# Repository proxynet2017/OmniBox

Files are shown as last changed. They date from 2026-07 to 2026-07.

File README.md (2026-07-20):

<div align="center">

# OmniBox

**A public non-commercial ECU diagnostics and reprogramming interface platform**

OmniBox V1 is a KiCad-based USB-to-OBD and bench ECU interface designed for
serious diagnostic, protocol research and ECU reprogramming workflows.

OmniBox V1 board render






</div>

## What It Is

OmniBox is a public hardware and firmware project for building a capable vehicle
interface around documented, inspectable design files. The V1 board is intended
to be more than a simple USB-to-CAN adapter: it combines isolated USB, protected
vehicle power, multi-channel CAN/CAN-FD, K-line, J1850/SWCAN hardware stages,
programmable FEPS generation, measurement feedback and an OBD routing matrix.

The hardware is designed to support ECU communication and reprogramming
workflows both through OBD and on the bench. That includes the physical-layer
building blocks normally needed for flashing-oriented work: controlled vehicle
side power, routable diagnostic lines, FEPS generation, CAN/CAN-FD, K-line and
feedback measurements. Firmware support is still in early development, so this
should be read as a hardware capability and project direction, not a claim that
all reprogramming workflows are already validated.

## Why It Exists

Most low-cost diagnostic interfaces are closed, narrow or difficult to inspect.
OmniBox takes the opposite approach:

| Goal | What V1 Provides |
|---|---|
| Inspectable hardware | KiCad schematic, PCB, footprints, BOM and production files |
| Real ECU work | OBD and bench-oriented routing, FEPS and multiple bus interfaces |
| Electrical resilience | Isolation, TVS protection, protected power input and automotive parts |
| Firmware headroom | STM32H723 Cortex-M7 with native FDCAN and enough RAM for queues/traces |
| Community development | Public J2534/ELM327 firmware base and host-side test tools |
| Reproducibility | Gerbers, drill files, enclosure files and release assets |

## Current Releases

| Package | Version | Link |
|---|---:|---|
| Hardware manufacturing package | 1.0 beta | [hardware-v1.0-beta](https://github.com/proxynet2017/OmniBox/releases/tag/hardware-v1.0-beta) |
| Firmware source and binaries | 0.1 dev | [firmware-v0.1-dev](https://github.com/proxynet2017/OmniBox/releases/tag/firmware-v0.1-dev) |

Firmware release assets include `.elf`, `.bin`, `.hex`, `.map` and source
archive files.

## 3D Preview

The board can be inspected as a rendered image or as a STEP model:

- [board render PNG](docs/images/omnibox-v1-board-iso-complete.png)
- [board STEP model](docs/3d/omnibox-v1-board-complete.step)

## Hardware Highlights

| Area | OmniBox V1 |
|---|---|
| Host connection | Isolated USB Full-Speed with WinUSB and CDC interfaces |
| MCU | STM32H723ZGTx Cortex-M7 |
| CAN / CAN-FD | Five routable CAN-capable channels |
| CAN physical layer | NXP TJA1463 automotive CAN SIC transceivers |
| External CAN-FD | Microchip MCP2518FD controllers over SPI |
| K-line | Three ST L9637D ISO 9141-2 / ISO 14230 channels |
| SWCAN / J1850 | Dedicated Single-Wire CAN, VPW and PWM hardware stages |
| FEPS | Programmable boost stage with DAC control and ADC/current feedback |
| Routing | Relay and protected analog-switch matrix for OBD/J1962 pins |
| Protection | SM8S24A TVS, ESD/TVS protection, filtering and protected power input |
| Isolation | Isolated power, isolated I2C and digital isolators |
| Mechanical | Sheet-metal enclosure plus STEP/STL printable/mechanical files |

## Reprogramming-Oriented Design

OmniBox V1 was designed with ECU flashing and calibration workflows in mind,
including both in-vehicle OBD work and bench harness work.

Hardware features relevant to that goal:

- routable CAN/CAN-FD channels for modern ECU and gateway communication;
- multiple K-line channels for older ISO 9141-2 / ISO 14230 ECUs;
- J1850/SWCAN hardware stages for less common physical layers;
- programmable FEPS generation rather than a blind fixed rail;
- voltage and current feedback around the FEPS stage;
- controlled routing to OBD/J1962 pins;
- galvanic isolation between PC and vehicle domains;
- protected vehicle-side supply input and transient handling;
- enough MCU performance for transport queues, timing and future flashing logic.

The public firmware currently focuses on the J2534 and ELM327 base. The board is
intended to grow into a reliable open non-commercial flashing-capable platform,
but protocol coverage and validation still need contributors and hardware
testing.

## Main Component Choices

### STM32H723ZGTx

The STM32H723 gives the project room to grow. Its Cortex-M7 core, native FDCAN
peripherals, USB device support and memory headroom make it suitable for timing
sensitive transport work, buffering, trace collection and future protocol logic.

The firmware is bare-metal C using CMSIS, STM32H7 HAL and TinyUSB. This keeps
the stack understandable and avoids hiding protocol behavior behind a large
opaque framework.

### NXP TJA1463 and Microchip MCP2518FD

The board combines native STM32 FDCAN peripherals with external MCP2518FD
controllers to reach five CAN-capable channels. TJA1463 automotive CAN SIC
transceivers provide a modern physical layer suitable for CAN-FD experiments and
cleaner signaling margins than older generic CAN transceivers.

### ST L9637D K-line

Three L9637D channels are included so K-line support is not treated as a single
legacy pin. This matters for bench ECUs and vehicles where routing assumptions
are not always simple.

### FEPS Stage

The FEPS stage uses an LT8362 boost controller with MCP4922 DAC control, INA240
current measurement and MCP3426 ADC feedback. The point is controllability:
firmware can supervise and sequence a programming voltage instead of blindly
switching a fixed output.

### Isolation and Protection

The host side and vehicle side are separated with isolated digital channels,
isolated I2C and isolated power. Vehicle power is handled through a protected
input stage, high-energy TVS protection and an LM61460-Q1 regulator.

That architecture is deliberate. It reduces PC-side exposure during bench work,
makes ground domains easier to reason about and gives reviewers clear protection
blocks to inspect.

### Routing Matrix

The routing matrix uses relays and protected ADG5412F analog switches to map
interfaces to OBD/J1962 pins. This makes the board useful for more than one
fixed pinout and reduces external wiring changes during protocol development.

## Public Firmware

Firmware version `0.1 dev` is an early public development release.

Present today:

- TinyUSB device stack;
- WinUSB vendor bulk transport for J2534-oriented communication;
- CDC serial interface for ELM327-style commands;
- public USB mode switching command;
- multi-identity framework with empty public experimental slots;
- board driver structure for CAN/CAN-FD, K-line, J1850/SWCAN, FEPS and routing;
- host-side tests and virtual device tooling.

Still in progress:

- complete J2534 behavior and edge cases;
- protocol timing under real load;
- ISO-TP long transfers;
- K-line initialization and timing validation;
- SWCAN and J1850 firmware support;
- FEPS sequencing and safety interlocks;
- more ELM327 compatibility;
- Windows packaging and broader host validation;
- real ECU bench and OBD test matrix.

## Build Firmware

Prerequisites:

- `arm-none-eabi-gcc`;
- CMake;
- Ninja;
- Git access for pinned dependencies.

```bash
cmake -S firmware -B firmware/build -G Ninja \
  -DCMAKE_TOOLCHAIN_FILE=cmake/arm-gcc.cmake \
  -DCMAKE_BUILD_TYPE=Release
cmake --build firmware/build
```

Expected outputs:

- `firmware/build/firmware.elf`
- `firmware/build/firmware.bin`
- `firmware/build/firmware.hex`
- `firmware/build/firmware.map`

## Manufacturing Files

| File | Purpose |
|---|---|
| `hardware/omnibox-v1/omnibox-v1.kicad_pro` | KiCad project |
| `hardware/omnibox-v1/omnibox-v1.kicad_sch` | Main schematic |
| `hardware/omnibox-v1/omnibox-v1.kicad_pcb` | PCB layout |
| `hardware/omnibox-v1/production/bom-consolide.csv` | Consolidated BOM |
| `hardware/omnibox-v1/production/j2534-schematics.pdf` | Schematic PDF |
| `hardware/omnibox-v1/production/local-finish/j2534-gerbers-jlcpcb.zip` | Gerber archive |
| `hardware/omnibox-v1/enclosure/` | Sheet-metal and printable enclosure files |

The local-finish Gerber package was regenerated with KiCad 10.0.4 from the
corrected PCB. `D_PWR1` uses the definitive `SM8S24A` orientation.

Before ordering boards, review the schematic, PCB, BOM, component orientation,
DRC warnings, stack-up, solder mask, paste layers and enclosure fit with your
manufacturer or assembler.

## Repository Layout

```text
hardware/omnibox-v1/    KiCad board, production files and enclosure
firmware/               STM32H723 firmware
host/                   J2534 DLL, virtual device and PC-side tools
docs/                   Images and public documentation
LICENSE.md              Public non-commercial license and commercial notice
SUPPORT.md              Donations, sponsoring and contribution information
FORUM_POST.md           Forum presentation draft
```

## Looking For Contributors

Useful help areas:

- board review and DRC/manufacturing feedback;
- automotive protection and isolation review;
- BOM validation and alternate parts;
- J2534 implementation and tests;
- ELM327 compatibility;
- K-line, J1850, SWCAN and FEPS firmware work;
- ECU bench validation;
- Windows host tooling and packaging;
- enclosure/mechanical improvements;
- documentation and test procedures.

If you can test on real ECUs, review automotive analog hardware or help turn the
existing hardware blocks into reliable firmware features, your contribution is
especially valuable.

## License

OmniBox is public for non-commercial use only.

Commercial use, commercial manufacturing, resale, paid services, commercial
integration and commercial distribution require prior written permission from the
maintainer. See [LICENSE.md](LICENSE.md) for the full terms and [SUPPORT.md](SUPPORT.md)
for donation, sponsoring and commercial licensing information.

## Safety Notice

OmniBox connects to vehicle communication lines and can generate programming
voltages. Hardware errors, assembly mistakes, firmware defects, incorrect
routing, unsuitable test conditions or misuse can damage ECUs, vehicles,
computers, tools or data.

Use the design only if you understand the electrical and legal risks. Review and
test the hardware before connecting it to anything valuable.

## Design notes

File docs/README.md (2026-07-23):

# Public notes

This directory is reserved for public OmniBox notes. Private research material is
not part of this repository.

- [OmniBox V1 Hardware Test Protocol](omnibox-v1-hardware-test-protocol.md)

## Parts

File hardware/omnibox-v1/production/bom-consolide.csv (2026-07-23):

Quantity | Manufacturer Part Number | Manufacturer Name | Description | Customer Reference | Source | Note
72 | CC0603KRX7R9BB104 | Yageo | Cond. 100nF 50V X7R 0603 10% | C18 C19 C20 C21 C22 C23 C24 C25 C26 C27 C28 C29 C30 C31 C32 C33 C56 C57 C58 C59 C60 C61 C62 C63 C64 C65 C66 C67 C68 C69 C70 C71 C72 C73 C74 C81 C82 C88 C89 C90 C_FE10 C_FE5 C_FE6 C_ISO1 C_KL1a1 C_KL1b1 C_KL2a1 C_KL2b1 C_KL3a1 C_KL3b1 C_MCU1 C_MCU10 C_MCU11 C_MCU2 C_MCU3 C_MCU4 C_MCU5 C_MCU6 C_MCU7 C_MCU8 C_MCU9 C_MCU_A1 C_MCU_A2 C_PWR1 C_PWR6 C_PWR9 C_RM2 C_RM4 C_RST1 C_SW1 C_USB2 C_VBAT1 | Mouser #280778508
27 | ERJ-3EKF1002V | Panasonic | Rés. 10k 1% 0603 | R17 R19 R21 R23 R24 R26 R27 R47 R_BOOT1 R_FE4 R_J18b1 R_J18e1 R_J18j1 R_J18o1 R_J18q1 R_J18r1 R_KL1c1 R_KL1d1 R_KL1e1 R_KL2c1 R_KL2d1 R_KL2e1 R_KL3c1 R_KL3d1 R_KL3e1 R_PWR6 R_RST1 | Mouser #280778508 | remplace RC0603FR-0710KL Yageo indispo
15 | SMAJ24CA | Littelfuse | TVS 24V uni 400W SMB | D_BN2 D_BN3 D_BN4 D_BN5 D_ESD1 D_ESD10 D_ESD11 D_ESD12 D_ESD13 D_ESD15 D_ESD2 D_ESD3 D_ESD7 D_ESD8 D_ESD9 | Mouser #280778508
13 | G6K-2F-Y-DC5 | Omron | Relais DPDT 5VDC signal | K_CAN2 K_CAN3 K_CAN4 K_GPT1 K_GPT2 K_J18 K_RM1 K_RM2 K_RM3 K_RM_F11 K_RM_F12 K_RM_F13 K_RM_F9 | Mouser #280778508 | graphie MPN corrigée (tiret)
8 | RC0603FR-0747KL | Yageo | Rés. 47k 1% 0603 | R18 R20 R22 R25 R28 R_KL1b1 R_KL2b1 R_KL3b1 | Mouser #280778508
5 | RC0603FR-07100KL | Yageo | Rés. 100k 1% 0603 | R_FE10 R_FE12 R_ISO3 R_PWR1 R_PWR7 | Mouser #280778508
6 | ISO7742DWR | Texas Instruments | Iso num. 4ch SOIC-16W | U_ISO10 U_ISO5 U_ISO6 U_ISO7 U_ISO8 U_ISO9 | Mouser #280778508
2 | GRM21BR61H106KE43K | Murata | Cond. 10uF 50V X5R 0805 | C_FE1 C_PWR4 | Mouser #280778508 | 50V obligatoire (rail VBAT) - derating DC a verifier (KE43K = ex-KE43L)
3 | GJ821BR61E106KE11L | Murata | Cond. 10uF 25V X5R 0805 | C_ISO2 C_SW2 C_USB1 | Mouser #280778508 | remplace CL21A106KAYNNNE Samsung indispo
5 | TJA1463AT/0Z | NXP | CAN SIC transceiver SO14 (SOIC-14 SOT108-1) | U_CAN1 U_CAN2 U_CAN3 U_CAN4T1 U_CAN5T1 | Farnell | remplace TJA1463ATK/0Z (HVSON14 leadless 3x4.5mm - empreinte incompatible) - a recommander
4 | CL10A105KB8NNNC | Samsung | Cond. 1uF 50V X5R 0603 | C_ISO6 C_ISO7 C_MCU_A3 C_PWR5 | Mouser #280778508
4 | RC0603FR-072K2L | Yageo | Rés. 2.2k 1% 0603 | R_ISO1 R_ISO2 R_RM1 R_RM2 | Mouser #280778508
4 | 08053D226MAT2A | KYOCERA AVX | Cond. 22uF 25V X5R 0805 | C_ISO8 C_ISO9 C_PWR7 C_PWR8 | Mouser #280778508 | remplace CL21A226MAQNNNE Samsung indispo
4 | 2N7002 | onsemi | MOSFET N 60V SOT-23 | Q_J18 Q_KL1 Q_KL2 Q_KL3 | Mouser #280778508
3 | RC0603FR-0718KL | Yageo | Rés. 18k 1% 0603 | R_KL1f1 R_KL2f1 R_KL3f1 | Mouser #280778508
3 | RC0603FR-071KL | Yageo | Rés. 1k 1% 0603 | R_ISO4 R_J18u1 R_LED2 | Mouser #280778508
3 | RC0603FR-0733RL | Yageo | Rés. 33 ohm 1% 0603 | R_J18c1 R_J18k1 R_J18m1 | Mouser #280778508
4 | RC0603FR-074K7L | Yageo | Rés. 4.7k 1% 0603 | R_FE2 R_J18h1 R_J18n1 R_J18t1 | Mouser #280778508
1 | C2012X5R1H475K125AB | TDK | Cond. 4.7uF 50V X5R 0805 | C_PWR3 | Mouser #280778508 | 50V obligatoire (rail VBAT) - remplace GRM21BR61H475KA73L Murata indispo
2 | CL21A475KAQNNNE | Samsung | Cond. 4.7uF 25V X5R 0805 | C_MCU_B1 C_MCU_B2 | Mouser #280778508
3 | ASE-40.000MHZ-LC-T | Abracon | Oscillateur XO 40MHz 3.3V 3225 CMOS | X_CAN1 X_CAN2 X_SW1 | Mouser #280778508 | VERIFIER: XO actif 4 broches, 3225, 1.8-3.3V
3 | RC0603FR-075K1L | Yageo | Rés. 5.1k 1% 0603 | R_J18i1 R_USB1 R_USB2 | Mouser #280778508
3 | RC0603FR-07510RL | Yageo | Rés. 510 ohm 1% 0603 | R_KL1a1 R_KL2a1 R_KL3a1 | Mouser #280778508
3 | ADG5412FBRUZ | Analog Devices | Switch analog. 4x SPST TSSOP-16 | U_RM_SW1 U_RM_SW2 U_RM_SW3 | Farnell
3 | 1N5819HW-7-F | Diodes Inc. | Schottky 40V 1A SOD-123 | D_FE2 D_J18a1 D_J18b1 | Mouser #280778508 | equivalent B5819W - remplace B5819WS-7-F indispo
3 | E-L9637D013TR | STMicroelectronics | Transceiver K-line ISO9141 SOIC-8 | U_KL1 U_KL2 U_KL3 | Mouser #280778508 | suffixe commande Mouser (meme composant)
3 | MCP2518FDT-E/SL | Microchip | Contrôleur CAN FD SPI SOIC-14 | U_CAN4 U_CAN5 U_SW_CTRL1 | Mouser #280778508
2 | CL10A106KP8NNNC | Samsung | Cond. 10uF 10V X5R 0603 | C_ISO4 C_ISO5 | Mouser #280778508
2 | CL32B106KBJNNNE | Samsung | Cond. 10uF 50V X7R 1210 | C_FE2 C_FE9 | Mouser #280778508 | remplace GRM32ER71H106KA12L Murata introuvable
2 | RC0603FR-0713KL | Yageo | Rés. 13k 1% 0603 | R_FE11 R_FE13 | Mouser #280778508
2 | CL10A225KO8NNNC | Samsung | Cond. 2.2uF 16V X5R 0603 | C38 C39 | Mouser #280778508
2 | RC0603FR-0720KL | Yageo | Rés. 20k 1% 0603 | R_J18d1 R_J18f1 | Mouser #280778508
2 | CL10B221KB8NNNC | Samsung | Cond. 220pF 50V X7R 0603 | C_J18a1 C_J18d1 | Mouser #280778508
2 | CL10C270JB8NNNC | Samsung | Cond. 27pF 50V C0G/NP0 0603 (charge quartz CL=18pF) | C_OSC1 C_OSC2 | Mouser #280778508
2 | RC0603FR-0733KL | Yageo | Rés. 33k 1% 0603 | R_PWR2 R_PWR3 | Mouser #280778508
2 | CL10B472KB8NNNC | Samsung | Cond. 4.7nF 50V X7R 0603 | C_FE7 C_RM3 | Mouser #280778508
2 | RC0603FR-07470KL | Yageo | Rés. 470k 1% 0603 | R_J18p1 R_J18s1 | Mouser #280778508
2 | RC0603FR-0760R4L | Yageo | Rés. 60.4 ohm 1% 0603 (term. CAN split 2x60.4=120.8) | R_RM4 R_RM5 | Mouser #280778508
2 | OPA192IDR | Texas Instruments | Ampli op précision SOIC-8 | U_J18A1 U_J18B1 | Mouser #280778508
2 | TCA9555PWR | Texas Instruments | Expandeur I/O I2C TSSOP-24 | U_RM2 U_RM4 | Mouser #280778508 | remplace PCA9555PW NXP indispo (compatible)
2 | ESDCAN06-2BLY | STMicroelectronics | TVS ESD CAN FD 36V SOT-23 | D_BN1 D_ESD6 | Farnell | ACHETÉ ESDCAN06-2BLY (Farnell) — variante SOT-23 valide ; ni VT-Q ni LQC-QZ | variante CANFD SOT-23 (remplace PESD2CAN NRND) - NE PAS prendre PESD2CANFD36LQC-QZ (DFN1412D-3 leadless
2 | SSA34-E3/5AT | Vishay | Schottky 40V 3A SMA (DO-214AC) | D_ISO1 D_ISO2 | Farnell | MPN précis Vishay commandé chez Farnell | remplace SS34 onsemi (DO-214AB/SMC - trop gros pour empreinte D_SMA) - a recommander
2 |  | (non mappé) | SolderJumper_2_Open / SolderJumper-2_P1.3mm_Open_Pad1.0x1.5mm | JP_BOOT1 JP_ISO1 | à sourcer / stock | !! MPN A DEFINIR
2 | ULN2003ADR | Texas Instruments | Driver Darlington 7ch SOIC-16 | U_RM3 U_RM5 | Mouser #280778508
1 | CRCW06030000Z0EA | Vishay | Rés. 0 ohm jumper 0603 | R_PWR4 | Mouser #280778508 | remplace RC0603JR-070RL Yageo
1 | WSL2512R2000FTB | Vishay | Rés. shunt 0.2 ohm 1% 1W 2512 | R_FE6 | Mouser #280778508 | VERIFIER puissance/precision shunt courant FEPS - remplace CSR2512-R200F
1 | 0451005.MRL | Littelfuse | Fusible Nano2 5A 125V CMS | F1 | Mouser #280778508
1 | UWT1H101MNL1GS | Nichicon | Cond. élec. 100uF 50V SMD 8x10.5 | C_PWR2 | Mouser #280778508 | equivalent ; verifier hauteur boitier - remplace EEE-FK1H101P Panasonic indispo
1 | CL10B103KB8NNNC | Samsung | Cond. 10nF 50V X7R 0603 | C_FE4 | Mouser #280778508
1 | PJ-102AH | CUI Devices | Jack alim 2.5mm THT coudé | J_PWR1 | Mouser #280778508
1 | RC0603FR-0714K3L | Yageo | Rés. 14.3k 1% 0603 | R_FE5 | Mouser #280778508
1 | RC0603FR-0714KL | Yageo | Rés. 14k 1% 0603 | R_J18a1 | Mouser #280778508
1 | RC0603FR-0715KL | Yageo | Rés. 15k 1% 0603 | R_J18l1 | Mouser #280778508
1 | CL10B102KB8NNNC | Samsung | Cond. 1nF 50V X7R 0603 | C_J18c1 | Mouser #280778508
1 | 1812HC222KAT2A | KYOCERA AVX | Cond. 2.2nF 3kV X7R 1812 (pont barriere iso, Mouser 581-1812HC222KAT2A) | C_Y1 | Mouser #280778508 | 3kV = marge sur barriere 2.5kV. Alt KEMET ArcShield ou Johanson 1812 3kV
1 | CL32B225KBJNNNE | Samsung | Cond. 2.2uF 50V X7R 1210 | C_FE8 | Mouser #280778508 | remplace C3225X7R1H225K TDK indispo
1 | 74404042022 | Würth | Inductance 2.2uH ~4.8A 4x4 | L_ISO1 | Mouser #280778508 | equivalent buck AP63203
1 | RC0603FR-0722KL | Yageo | Rés. 22k 1% 0603 | R_FE14 | Mouser #280778508
1 | ABM8-25.000MHZ-B2-T | Abracon | Quartz 25MHz 3225 CL=18pF ESR<=50ohm (datasheet confirme) | Y1 | Mouser #280778508 | caps charge associees = 27pF (C_OSC1/2)
1 | RC1206FR-074K7L | Yageo | Rés. 4.7k 1% 1206 | R_FE9 | Mouser #280778508
1 | CL10A475KO8NNNC | Samsung | Cond. 4.7uF 16V X5R 0603 | C_FE3 | Mouser #280778508
1 | SRP1250-4R7M | Bourns | Inductance 4.7uH ~15A blindée | L_PWR1 | Mouser #280778508 | equivalent buck LM61460 ; verifier empreinte 12x12 - remplace SRP1245A-4R7M (equiv.)
1 | RC0603FR-0744K2L | Yageo | Rés. 44.2k 1% 0603 | R_PWR5 | Mouser #280778508
1 | RC0603FR-07470RL | Yageo | Rés. 470 ohm 1% 0603 | R_LED1 | Mouser #280778508
1 | RC0603FR-076K04L | Yageo | Rés. 6.04k 1% 0603 | R_SW1 | Mouser #280778508
1 | RC0603FR-076K2L | Yageo | Rés. 6.2k 1% 0603 | R_J18g1 | Mouser #280778508
1 | RC0603FR-0760K4L | Yageo | Rés. 60.4k 1% 0603 | R_FE1 | Mouser #280778508
1 | RC0603FR-0782K5L | Yageo | Rés. 82.5k 1% 0603 | R_FE3 | Mouser #280778508
1 | AP2112K-3.3TRG1 | Diodes Inc. | LDO 3.3V 600mA SOT-25 | U_ISO3 | Mouser #280778508
1 | AP63203WU-7 | Diodes Inc. | Buck 2A 3.8-32V TSOT-23-6 | U_ISO1 | Mouser #280778508
1 |  | (générique) | Header 2x5 1.27mm SWD (optionnel) | J_SWD1 | à sourcer / stock | montage manuel optionnel - choisir au choix
1 | L77SDB25SA4CH4F | Amphenol | DB25 femelle coudée CMS-THT | J1 | Mouser #280778508 | CONSIGNE: doit matcher cable Scanmatik - confirmer modele coudé bord de carte
1 | BLM18AG601SN1D | Murata | Ferrite 600ohm@100MHz 0603 | FB1 | Mouser #280778508 | remplace BLM18PG600SN1D (equiv. 600ohm)
1 | INA240A1DR | Texas Instruments | Ampli mesure courant g=20 SOIC-8 | U_FE3 | Mouser #280778508
1 | ISO1640QDWRQ1 | Texas Instruments | Iso I2C bidir. SOIC-16W 5kVrms | U_ISO4 | Mouser #280922872 | ref sans B (B=SOIC-8 ISO1640BQDRQ1); JLCPCB C5216231
1 | ISO7741DWR | Texas Instruments | Iso num. 4ch SOIC-16W | U_ISO11 | Mouser #280778508
1 | LM339DR | Texas Instruments | Comparateur quad SOIC-14 | U_J18C1 | Mouser #280778508
1 | LM61460AASQRJRRQ1 | Texas Instruments | Buck 3A auto VQFN-HR-14 | U_PWR2 | Mouser #280778508 | verifier suffixe exact - variante AAS (remplace AAQ indispo)
1 | LM74700QDBVTQ1 | Texas Instruments | Ctrl diode idéale anti-inversion SOT-23-6 | U_PWR1 | Mouser #280778508 | variante T (bande) du DBVR
1 | LT8362EDD#TRPBF | Analog Devices | Régulateur boost/SEPIC 60V DFN-10 | U_FE1 | Farnell
1 | MCP3426A0-E/SN | Microchip | ADC 16-bit 2ch I2C SOIC-8 | U_FE4 | Mouser #280778508
1 | MCP4922-E/SL | Microchip | DAC 12-bit 2ch SPI SOIC-14 | U_FE2 | Mouser #280778508
1 | NCV7356D1R2G | onsemi | Transceiver single-wire CAN SOIC-8 | U_SW1 | Mouser #280778508
1 | SM8S24A | Littelfuse | TVS load-dump 24V auto DO-218AB | D_PWR1 | Mouser #280778508 | verifier fabricant (Littelfuse/Bourns)
1 | SMBJ5.0A | Littelfuse | TVS 5V uni 600W SMB | D_USB3 | Mouser #280778508
1 | SN6505BDBVR | Texas Instruments | Driver transfo push-pull SOT-23-6 | U_ISO2 | Mouser #280778508
1 | SRF1260A-220M | Bourns | Inductance couplée 22uH SEPIC AEC-Q200 (Mouser 652-SRF1260A-220M) | L_FE1 | Mouser #280778508 | verifier empreinte L_Coupled_1260 ; alt. Würth 744878220
1 | SSA36 | onsemi | Schottky 60V 3A SMA (DO-214AC) | D_FE1 | Farnell | remplace SS36 onsemi (DO-214AB/SMC - trop gros pour empreinte D_SMA) - a recommander
1 | SS54-HF | Kingtronics | Schottky 40V 5A SMA | D_PWR2 | Mouser #280778508 | variante halogen-free
1 | STD20NF06LT4 | STMicroelectronics | MOSFET N 60V 24A DPAK | Q_PWR1 | Mouser #280778508
1 | STM32H723ZGT6 | STMicroelectronics | MCU Cortex-M7 LQFP-144 | U1 | Mouser #280778508 | CONSIGNE (non LCSC) ; alt STM32H733ZGT6
1 | USBLC6-2SC6Y | STMicroelectronics | Protection ESD USB SOT-23-6 | D_USB1 | Mouser #280778508 | variante Y (automotive) du USBLC6-2SC6
1 | USB4085-GF-A | GCT | Connecteur USB-C récept. CMS | J_USB1 | Mouser #280778508
1 | 750315371 | Würth | Transfo isolé push-pull WE-PPTI | T1 | Mouser #280778508 | CONSIGNE (Mouser/Würth direct)
1 | 150060VS75000 | Würth | LED verte 0603 | LED_PWR1 | Mouser #280778508 | alim hôte
1 | 150060RS75000 | Würth | LED rouge 0603 | LED_H1 | Mouser #280778508 | statut MCU
1 | 150060VS75000 | Würth | LED verte 0603 | LED_V1 | Mouser #280778508 | présence alim véhicule

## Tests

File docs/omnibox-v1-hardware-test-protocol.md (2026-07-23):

# OmniBox V1 Hardware Test Protocol

Step-by-step bring-up protocol for one assembled OmniBox V1 board.

Allowed equipment:

- Fluke 287 DMM;
- PC with USB-C;
- external 12 V bench supply with adjustable current limit.

No DB25 fixture, oscilloscope, logic analyzer, ECU or vehicle is required for this protocol.

## 1. Scope

This protocol validates:

- input protection sanity and no-short state;
- USB-side power, firmware startup and enumeration;
- isolated vehicle-side rails from USB;
- 12 V vehicle-domain power path;
- default safe routing state;
- CAN recessive bias on directly exposed CAN channels;
- K-line recessive levels;
- FEPS safe-off state;
- ELM327 CDC command surface;
- J2534 USB mode access where a Windows PC is available.

Still not validated by this protocol:

- real CAN/CAN-FD frames on a terminated bus;
- ISO9141/KWP traffic against a real ECU;
- J1850 waveform timing;
- SWCAN wake/signaling;
- FEPS regulation under load;
- vehicle/ECU compatibility.

Do not connect the board to a vehicle or ECU until those deferred tests have been completed.

## 2. Software Preparation

Run from the repository root:

```bash
cd /path/to/OmniBox   # repository root
./host/test/run_tests.sh

cd firmware
cmake -B build -G Ninja -DCMAKE_TOOLCHAIN_FILE=cmake/arm-gcc.cmake
cmake --build build
```

Expected:

- all host tests pass;
- `firmware/build/firmware.elf`, `firmware/build/firmware.bin` and `firmware/build/firmware.hex` are generated;
- firmware version string is `OmniBox FW 0.1 dev HW:1.0 beta`.

Flash `firmware/build/firmware.bin` or `firmware/build/firmware.elf` using the STM32H723 flashing method used on your bench, then continue.

## 3. Measurement Rules

General rules:

- Unpowered resistance and diode checks: no USB, no 12 V.
- Voltage checks: black probe on the correct ground domain.
- Vehicle-domain reference: `GND_V`, DB25 pin 4, 5 or 17.
- Host-domain reference: `GND_H`, USB-side ground.
- Never intentionally short `GND_H` and `GND_V`.
- Use Fluke `REL` before low-resistance measurements.
- Current is read on the bench supply display unless a series current measurement is explicitly required.

Practical probe points:

| Net | Probe point |
|---|---|
| `VBAT` | DB25 pin 16, 23 or 24, or the 12 V input jack |
| `VBAT_PROT` | Q_PWR1 drain tab, C_PWR2 positive terminal, D_PWR1 cathode |
| `V5_BUCK` | L_PWR1 output, C_PWR7, D_PWR2 anode |
| `5V_V` | D_PWR2 cathode, U_KL1/U_KL2/U_KL3 pin 3 |
| `3V3_V` | U_ISO3 output, R_ISO4 vehicle-side LED resistor |
| `VFEPS` | DB25 pin 25 |
| `GND_V` | DB25 pin 4, 5 or 17 |
| `GND_H` | USB-side ground near the USB connector |
| `3V3_H` | USB-side 3.3 V rail |

DB25 orientation: viewed from the outside of the female connector, top row is pins 1 to 13, bottom row is pins 14 to 25.

## 4. DB25 Quick Reference

| Pin | Default function |
|---:|---|
| 1 | routed OEM pin, default open |
| 2 | J1850 BUS+ static path |
| 3 | routed OEM pin, default open |
| 4 | `GND_V` |
| 5 | `GND_V` |
| 6 | CAN1-H |
| 7 | K-line 1 fixed path |
| 8 | routed OEM pin, default open |
| 9 | routed OEM pin / FEPS candidate, default open |
| 10 | J1850 BUS- candidate, default open |
| 11 | routed OEM pin / FEPS candidate, default open |
| 12 | routed OEM pin / CAN swap / FEPS candidate, default open |
| 13 | routed OEM pin / CAN swap / FEPS candidate, default open |
| 14 | CAN1-L |
| 15 | routed OEM pin, default open |
| 16 | `VBAT` input |
| 17 | `GND_V` |
| 18 | GPT1 candidate, default open |
| 19 | GPT2 candidate, default open |
| 20 | CAN5-H |
| 21 | CAN5-L |
| 22 | K-line 3 fixed path |
| 23 | `VBAT` input |
| 24 | `VBAT` input |
| 25 | `VFEPS` output node with bleeder |

## 5. Phase 0 - Visual Inspection

Board disconnected from everything.

1. Inspect all fine-pitch packages for bridges: STM32, LM61460, MCP2518FD, TJA1463, PCA9555, ADG5412F and L9637.
2. Confirm polarized parts:
   - D_PWR1 is `SM8S24A`, not a bidirectional variant;
   - D_PWR1 cathode is on `VBAT_PROT`;
   - D_PWR1 anode is on `GND_V`;
   - D_PWR2 cathode is on `5V_V`;
   - D_FE1 cathode is on `VFEPS_RAW`;
   - D_ISO1 and D_ISO2 cathodes are on `5V_V`.
3. Confirm relay orientation against silkscreen.
4. Confirm no cracked, lifted or tombstoned component.

Pass: no visible fault and D_PWR1 orientation is certain.

## 6. Phase 1 - Unpowered Rail Checks

Board disconnected from USB and 12 V.

| Step | Fluke mode | Measurement | Expected result | Stop condition |
|---:|---|---|---|---|
| 1.1 | Ohms | DB25 pin 16 to `GND_V` | about 113 kOhm to 120 kOhm | below 10 kOhm |
| 1.2 | Ohms | `VBAT_PROT` to `GND_V` | no short, normally high impedance | below 10 kOhm |
| 1.3 | Ohms | `5V_V` to `GND_V` | above 10 kOhm | below 1 kOhm |
| 1.4 | Ohms | `3V3_V` to `GND_V` | above 10 kOhm | below 1 kOhm |
| 1.5 | Ohms | `3V3_H` to `GND_H` | no short | below 1 kOhm |
| 1.6 | Ohms | `VBUS` to `GND_H` | no short | below 1 kOhm |
| 1.7 | Ohms | `GND_H` to `GND_V` | above 10 MOhm | below 1 MOhm |
| 1.8 | Capacitance | `GND_H` to `GND_V` | about 2 nF to 3 nF | above 10 nF |

If any stop condition occurs, do not power the board.

## 7. Phase 2 - Unpowered Diode Checks

Board disconnected from USB and 12 V.

| Step | Fluke mode | Red lead | Black lead | Expected result |
|---:|---|---|---|---|
| 2.1 | Diode | `GND_V` | `VBAT_PROT` | about 0.5 V to 0.8 V |
| 2.2 | Diode | `VBAT_PROT` | `GND_V` | OL |
| 2.3 | Diode | `V5_BUCK` | `5V_V` | about 0.25 V to 0.45 V |
| 2.4 | Diode | `5V_V` | `V5_BUCK` | OL |
| 2.5 | Diode | DB25 pin 16 | `VBAT_PROT` | about 0.4 V to 0.7 V |
| 2.6 | Diode | `VBAT_PROT` | DB25 pin 16 | OL |

Meaning:

- 2.1 and 2.2 validate the definitive `SM8S24A` polarity.
- 2.3 and 2.4 validate the buck-to-vehicle-5V OR-ing diode.
- 2.5 and 2.6 validate input-path continuity through F1/body-diode and reverse blocking.

## 8. Phase 3 - Default Static Routing Checks

Board unpowered.

| Step | Fluke mode | Measurement | Expected result |
|---:|---|---|---|
| 3.1 | Ohms, REL | DB25 pin 6 to pin 14 | about 121 Ohm |
| 3.2 | Ohms | DB25 pin 20 to pin 21 | above 10 kOhm |
| 3.3 | Ohms, REL | DB25 pin 7 to `VBAT_PROT` | about 510 Ohm |
| 3.4 | Ohms, REL | DB25 pin 22 to `VBAT_PROT` | about 510 Ohm |
| 3.5 | Ohms, REL | DB25 pin 7 to pin 22 | about 1020 Ohm |
| 3.6 | Ohms | DB25 pin 2 to `GND_V` | about 7.5 kOhm |
| 3.7 | Ohms | DB25 pin 10 to `GND_V` | high impedance |
| 3.8 | Ohms | DB25 pin 25 to `GND_V` | about 4.5 kOhm |
| 3.9 | Ohms | DB25 pin 18 to pin 25 | OL |
| 3.10 | Ohms | DB25 pin 19 to pin 25 | OL |
| 3.11 | Ohms | DB25 pins 9, 11, 12, 13 to pin 25 | OL |
| 3.12 | Ohms | DB25 pin pairs 3-11, 12-13, 1-9 | OL |

Pass:

- CAN1 default termination is present.
- CAN5 has no onboard termination.
- K-line fixed pull-ups are present.
- FEPS and GPT are open in the default safe state.

## 9. Phase 4 - USB-Only Power-Up

DB25 disconnected. Bench supply disconnected.

1. Connect USB-C to the PC.
2. Watch for a stable USB attach event.
3. Check enumeration.

Linux:

```bash
dmesg --follow
lsusb
ls -l /dev/serial/by-id/ 2>/dev/null || true
```

Windows:

```powershell
Get-PnpDevice -PresentOnly | findstr /i "OmniBox USB Serial WinUSB"
```

Expected:

- stable enumeration;
- no connect/disconnect loop;
- in mode 0, one WinUSB vendor interface and one CDC serial interface.

If the PC reports USB over-current, unplug immediately and return to Phase 1.

## 10. Phase 5 - USB-Only Rail Measurements

Board connected to USB only.

| Step | Measurement | Reference | Expected result |
|---:|---|---|---|
| 5.1 | `VBUS` | `GND_H` | about 5.0 V |
| 5.2 | `3V3_H` | `GND_H` | about 3.3 V |
| 5.3 | `5V_V` | `GND_V` | about 5.0 V to 5.5 V |
| 5.4 | `3V3_V` | `GND_V` | about 3.3 V |
| 5.5 | `VBAT_PROT` | `GND_V` | near 0 V |
| 5.6 | DB25 pin 25 | `GND_V` | near 0 V |

Pass:

- host and isolated vehicle rails are present;
- USB does not significantly back-power `VBAT_PROT`;
- FEPS output remains off.

## 11. Phase 6 - 12 V Power-Up Without USB

USB disconnected. DB25 disconnected except power input.

1. Set the bench supply to 12.0 V.
2. Set current limit to 200 mA.
3. Connect supply positive to DB25 pin 16, 23 or 24, or to the 12 V input jack.
4. Connect supply negative to DB25 pin 4, 5 or 17.
5. Turn the supply on.
6. Observe current for 30 seconds.

Expected:

- brief inrush is acceptable;
- steady current should be about 60 mA to 160 mA;
- no component should become hot;
- U_FE1 must remain cold because FEPS is off.

Stop immediately if:

- current stays at the 200 mA limit;
- a component heats quickly;
- `VFEPS` rises unexpectedly.

## 12. Phase 7 - 12 V Rail Measurements

Board powered from 12 V bench supply only.

| Step | Measurement | Reference | Expected result |
|---:|---|---|---|
| 7.1 | DB25 pin 16 | `GND_V` | bench voltage, about 12.0 V |
| 7.2 | `VBAT_PROT` | `GND_V` | about 11.95 V to 12.05 V |
| 7.3 | `V5_BUCK` | `GND_V` | about 5.4 V |
| 7.4 | `5V_V` | `GND_V` | about 5.0 V to 5.2 V |
| 7.5 | `3V3_V` | `GND_V` | about 3.3 V |
| 7.6 | DB25 pin 25, `VFEPS` | `GND_V` | near 0 V |
| 7.7 | FEPS controller `INTVCC`, if accessible | `GND_V` | near 0 V |
| 7.8 | VBATT sense divider node, if accessible | `GND_V` | about 1.36 V to 1.38 V at 12.0 V input |
| 7.9 | INA240 output, if accessible | `GND_V` | near 0 V |
| 7.10 | ADG5412F VDD, if accessible | `GND_V` | about `VBAT_PROT` |

Known-good bring-up references from the V1 hardware session:

- `VBAT_PROT`: about 12.0 V from 12.05 V input;
- `V5_BUCK`: about 5.4 V;
- `5V_V`: about 5.1 V;
- `3V3_V`: about 3.3 V;
- `VFEPS`: about 0.028 V;
- VBATT sense: about 1.358 V at 12 V input.

Pass: all accessible rails are in range and steady.

## 13. Phase 8 - 12 V Static Bus Levels

Board powered from 12 V bench supply only. USB still disconnected.

| Step | Measurement | Reference | Expected result |
|---:|---|---|---|
| 8.1 | DB25 pin 6, CAN1-H | `GND_V` | about 2.5 V |
| 8.2 | DB25 pin 14, CAN1-L | `GND_V` | about 2.5 V |
| 8.3 | DB25 pin 6 to pin 14 | differential V DC | near 0 V |
| 8.4 | DB25 pin 20, CAN5-H | `GND_V` | about 2.5 V |
| 8.5 | DB25 pin 21, CAN5-L | `GND_V` | about 2.5 V |
| 8.6 | DB25 pin 7, K-line 1 | `GND_V` | may be dominant without USB; record value |
| 8.7 | DB25 pin 22, K-line 3 | `GND_V` | may be dominant without USB; record value |
| 8.8 | DB25 pin 25, `VFEPS` | `GND_V` | near 0 V |

Notes:

- CAN recessive levels around 2.5 V validate transceiver power and idle bias.
- K-line levels without USB can be misleading because MCU-side control is not active. The decisive K-line check is Phase 10 with firmware running.

## 14. Phase 9 - Combined USB + 12 V Power

1. Keep the 12 V bench supply connected and current-limited to 300 mA.
2. Connect USB to the PC.
3. Wait for USB enumeration.
4. Observe 12 V input current.

Expected:

- stable USB enumeration;
- no reset loop;
- 12 V current remains stable, typically below 160 mA;
- `5V_V` remains about 5.0 V to 5.2 V;
- `3V3_V` remains about 3.3 V;
- `VFEPS` remains near 0 V.

Stop if the 12 V supply current jumps unexpectedly or if USB repeatedly disconnects.

## 15. Phase 10 - Firmware-Controlled Static Levels

Board powered from USB and 12 V. Firmware running in mode 0.

Set the USB identity to the public J2534 + ELM327 mode.

Windows hardware command:

```powershell
.\j2534mode.exe get
.\j2534mode.exe set j2534
```

Linux can only use `j2534mode` against the virtual TCP device in the current host tools; direct WinUSB hardware access is Windows-only.

Measure:

| Step | Measurement | Reference | Expected result |
|---:|---|---|---|
| 10.1 | DB25 pin 7, K-line 1 | `GND_V` | about 12 V, recessive |
| 10.2 | DB25 pin 22, K-line 3 | `GND_V` | about 12 V, recessive |
| 10.3 | DB25 pin 25, `VFEPS` | `GND_V` | near 0 V |
| 10.4 | DB25 pin 6, CAN1-H | `GND_V` | about 2.5 V |
| 10.5 | DB25 pin 14, CAN1-L | `GND_V` | about 2.5 V |
| 10.6 | DB25 pin 20, CAN5-H | `GND_V` | about 2.5 V |
| 10.7 | DB25 pin 21, CAN5-L | `GND_V` | about 2.5 V |

Pass:

- K-lines are recessive with firmware active;
- FEPS stays off;
- CAN buses remain recessive.

## 16. Phase 11 - ELM327 CDC Smoke Test

Board powered from USB. 12 V may remain connected.

Linux:

```bash
python3 - <<'PY'
import glob, time
import serial

ports = glob.glob('/dev/serial/by-id/*') + glob.glob('/dev/ttyACM*')
if not ports:
    raise SystemExit('No CDC serial port found')

p = serial.Serial(ports[0], 38400, timeout=0.05)

def transact(cmd, timeout=1.5):
    p.reset_input_buffer()
    p.write((cmd + '\r').encode())
    end = time.time() + timeout
    data = bytearray()
    while time.time() < end:
        chunk = p.read(64)
        if chunk:
            data.extend(chunk)
            if b'>' in data:
                break
    text = data.decode(errors='replace').replace('\r', '\n')
    lines = [line.strip() for line in text.split('\n')
             if line.strip() and line.strip() != '>']
    print(f'{cmd}: raw={bytes(data)!r} lines={lines}')

for cmd in ['ATZ', 'ATI', 'ATE0', 'ATL0', 'ATS0', 'ATSP0']:
    transact(cmd)
p.close()
PY
```

Windows PowerShell:

```powershell
$port = "COMx"
$sp = New-Object System.IO.Ports.SerialPort $port,38400,None,8,one
$sp.ReadTimeout = 1000
$sp.Open()
foreach ($cmd in "ATZ`r","ATI`r","ATE0`r","ATL0`r","ATS0`r","ATSP0`r") {
  $sp.Write($cmd)
  Start-Sleep -Milliseconds 200
  $sp.ReadExisting()
}
$sp.Close()
```

Expected:

| Command | Expected response |
|---|---|
| `ATZ` | reset banner or `ELM327 v1.5` |
| `ATI` | `ELM327 v1.5` |
| `ATE0` | `OK` |
| `ATL0` | `OK` |
| `ATS0` | `OK` |
| `ATSP0` | `OK` |

Do not expect `0100` or any OBD query to succeed without an ECU or simulator.

## 17. Phase 12 - J2534 PC Registration Check

Windows only. This checks PC integration, not bus traffic.

1. Build or install the OmniBox DLLs.
2. Edit `host/dll/j2534_register.reg` so `FunctionLibrary` points to the actual DLL path.
3. Import the registry file as Administrator.
4. Run:

```powershell
reg query "HKLM\SOFTWARE\PassThruSupport.04.04\OmniBox"
reg query "HKLM\SOFTWARE\WOW6432Node\PassThruSupport.04.04\OmniBox"
```

Expected:

- OmniBox is listed in both 64-bit and 32-bit PassThru locations;
- the registry does not advertise experimental protocols as stable.

## 18. Acceptance Sheet

Record each item as `PASS`, `FAIL` or `DEFERRED`.

| Item | Required result |
|---|---|
| Visual inspection | PASS |
| Unpowered rail checks | PASS |
| D_PWR1 `SM8S24A` diode orientation | PASS |
| D_PWR2 diode orientation | PASS |
| `GND_H` to `GND_V` isolation | PASS |
| Default CAN1 termination | PASS |
| Default FEPS/GPT open state | PASS |
| USB enumeration | PASS |
| USB-only `3V3_H` | PASS |
| USB-only `5V_V` and `3V3_V` | PASS |
| USB does not back-power `VBAT_PROT` | PASS |
| 12 V current at 200 mA limit | PASS |
| `VBAT_PROT`, `V5_BUCK`, `5V_V`, `3V3_V` from 12 V | PASS |
| `VFEPS` safe-off from 12 V | PASS |
| CAN1 and CAN5 recessive static levels | PASS |
| K-line 1 and K-line 3 recessive with firmware active | PASS |
| ELM327 AT command smoke test | PASS |
| J2534 Windows registration | PASS or DEFERRED if no Windows PC |
| Real CAN/CAN-FD traffic | DEFERRED |
| Real ISO9141/KWP traffic | DEFERRED |
| Real J1850/SWCAN traffic | DEFERRED |
| FEPS under load | DEFERRED |

The board passes this hardware protocol only when every non-deferred item is `PASS`.

## 19. Failure Rules

- If any low-voltage rail is below 1 kOhm to ground, do not power the board.
- If `GND_H` to `GND_V` is below 1 MOhm, do not power the board.
- If D_PWR1 diode polarity is wrong, do not apply 12 V.
- If 12 V current stays at the current limit, switch off immediately.
- If `VFEPS` rises without an explicit firmware command, switch off immediately.
- If a K-line remains dominant with firmware active, do not connect to an ECU.
- If CANH/CANL differential voltage is not near 0 V at idle, do not connect to a CAN bus.

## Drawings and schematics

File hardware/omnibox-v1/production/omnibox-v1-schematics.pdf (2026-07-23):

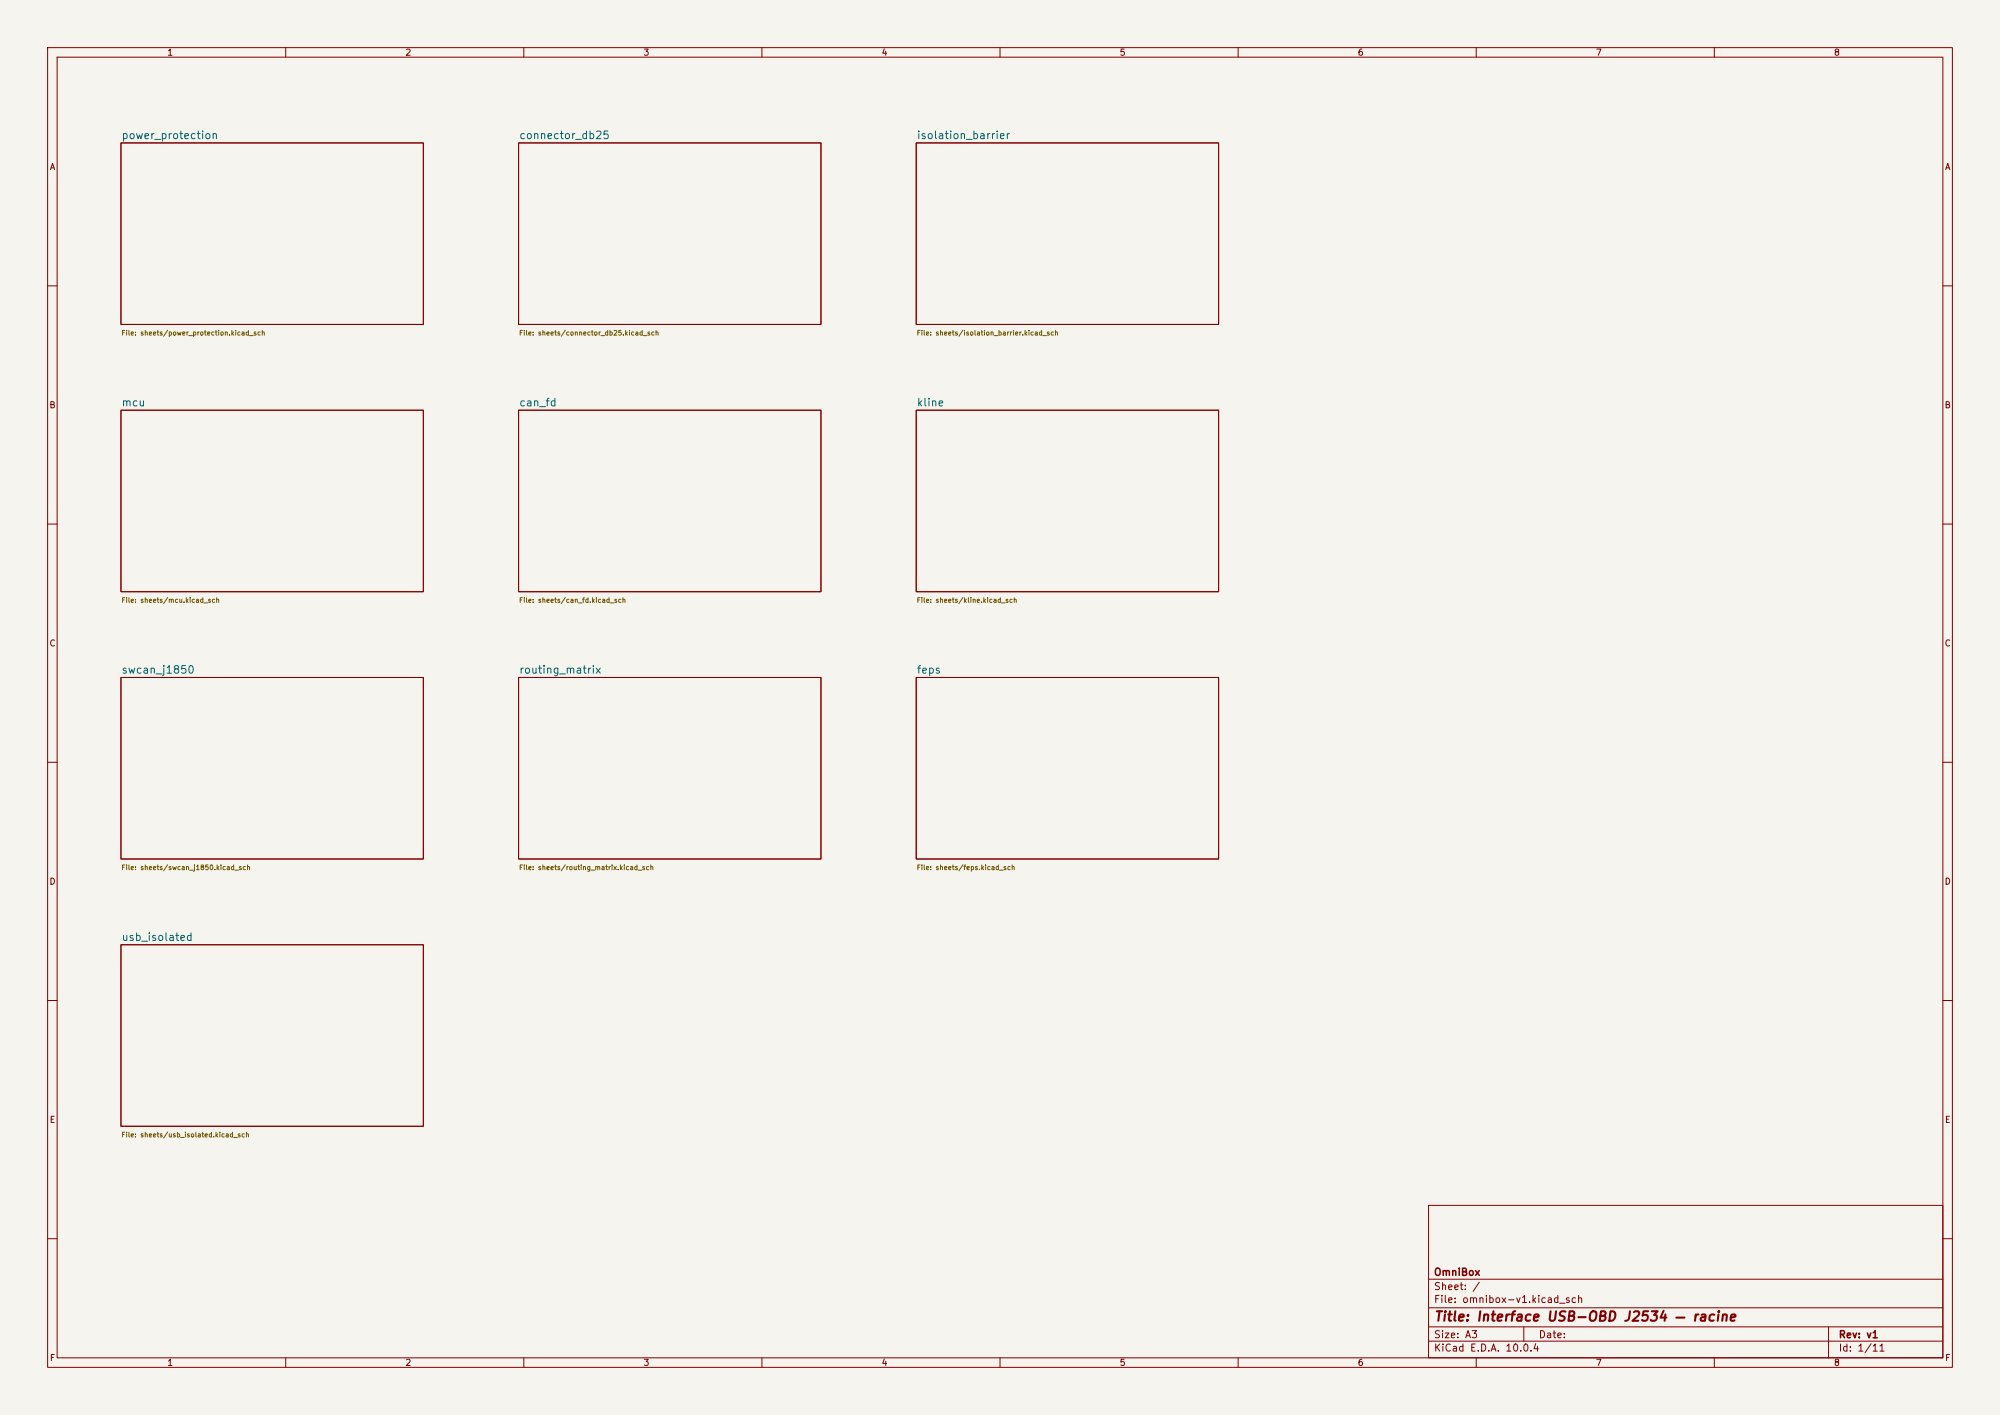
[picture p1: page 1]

OmniBox
Sheet: /
File: omnibox-v1.kicad_sch
Title: Interface USB-OBD J2534 — racine

Size: A3 | Rev: v1
KiCad E.D.A. 10.0.4 | Id: 1/11 | F Date:

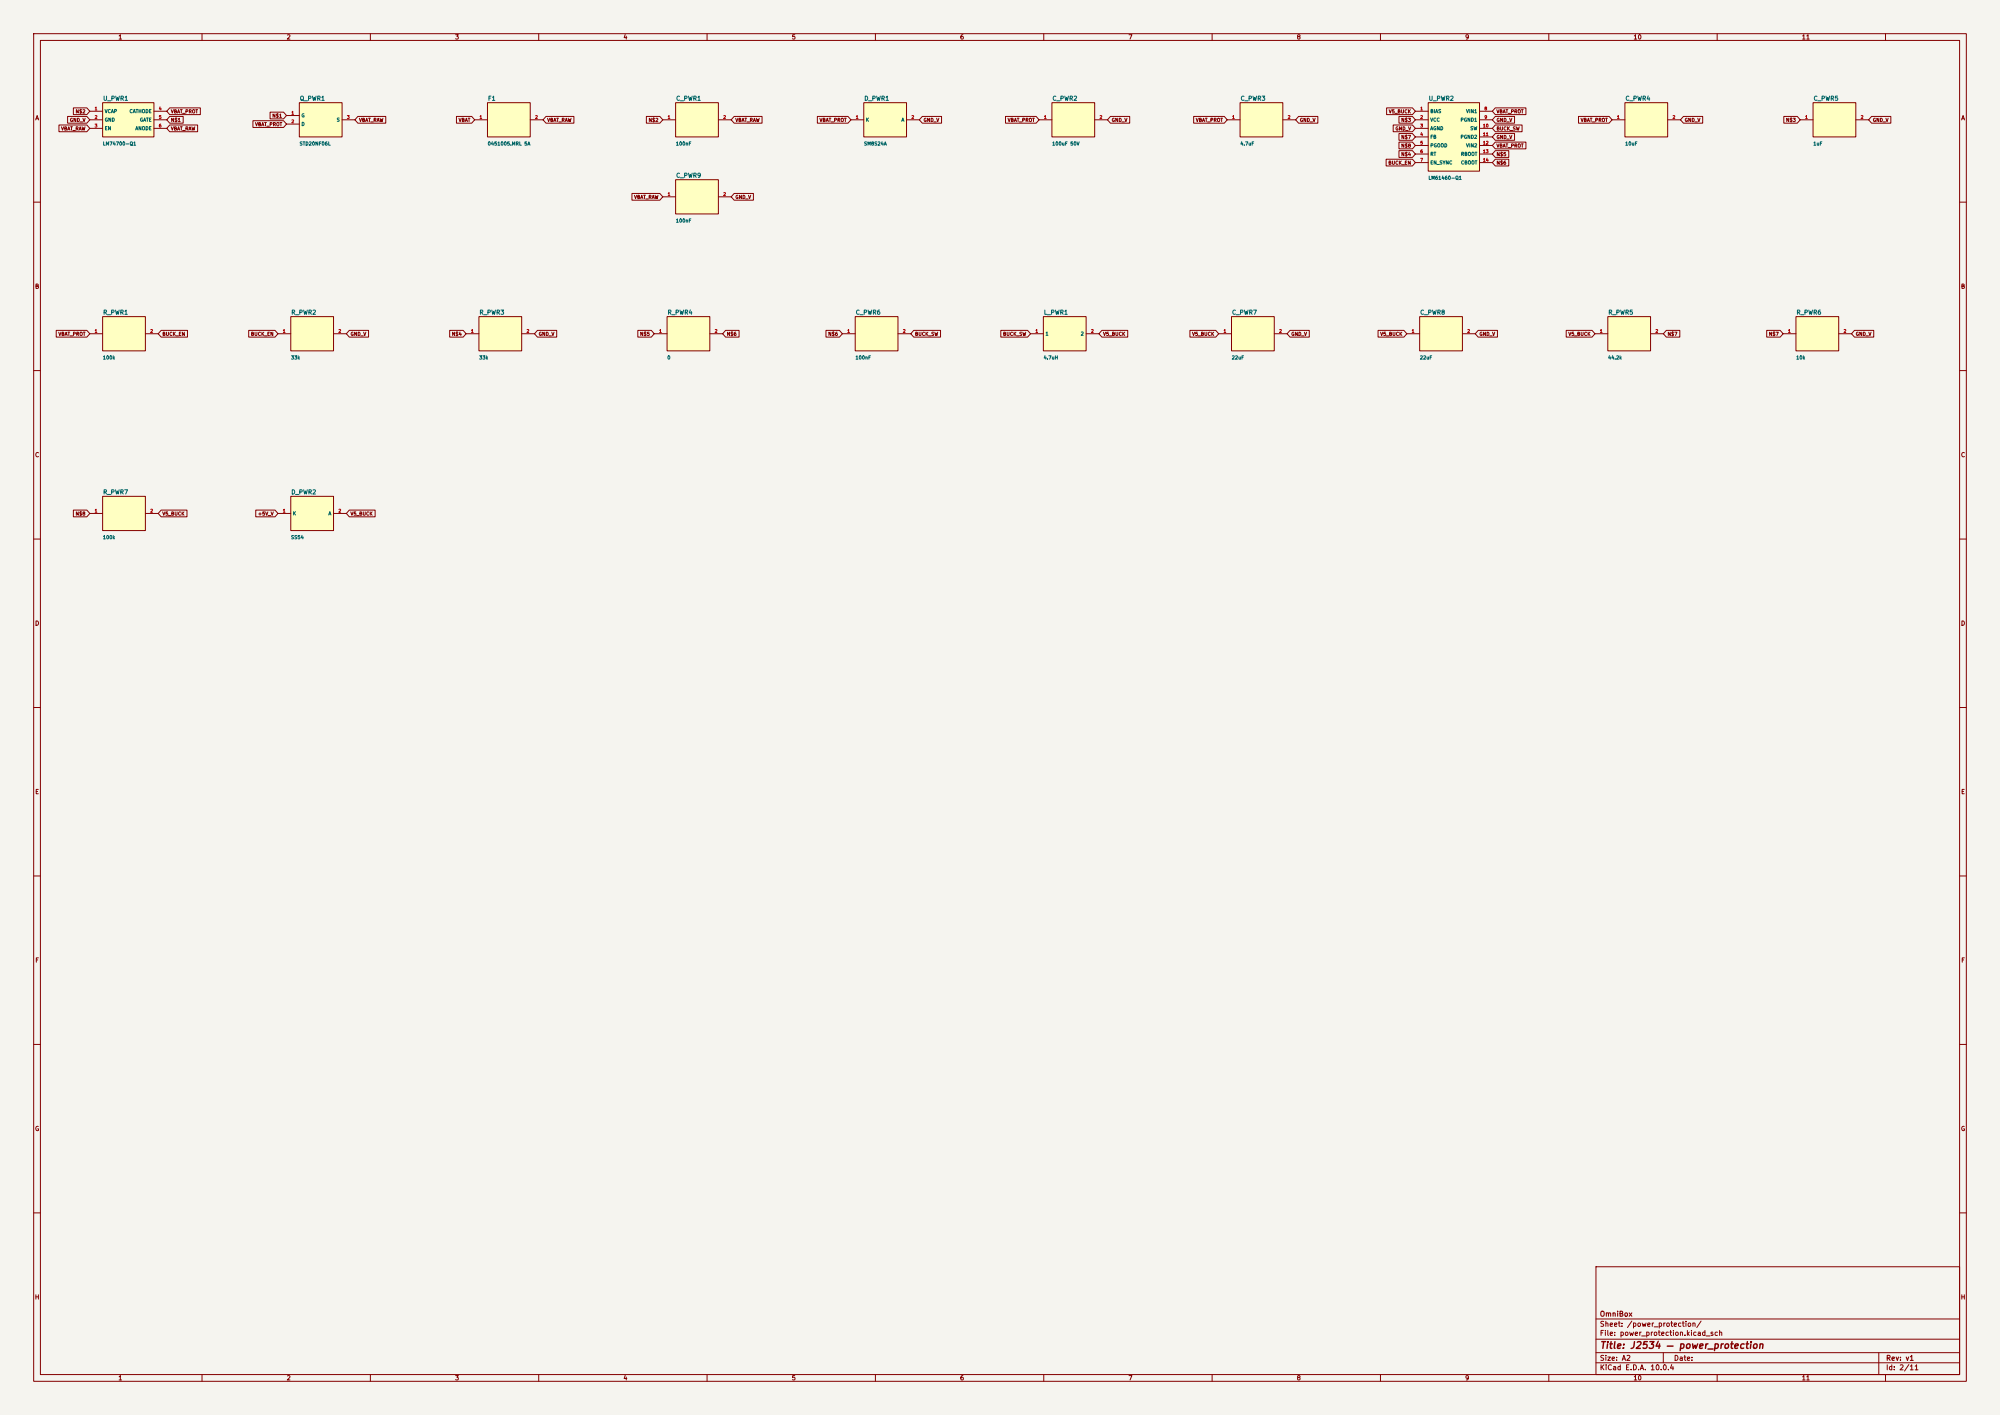
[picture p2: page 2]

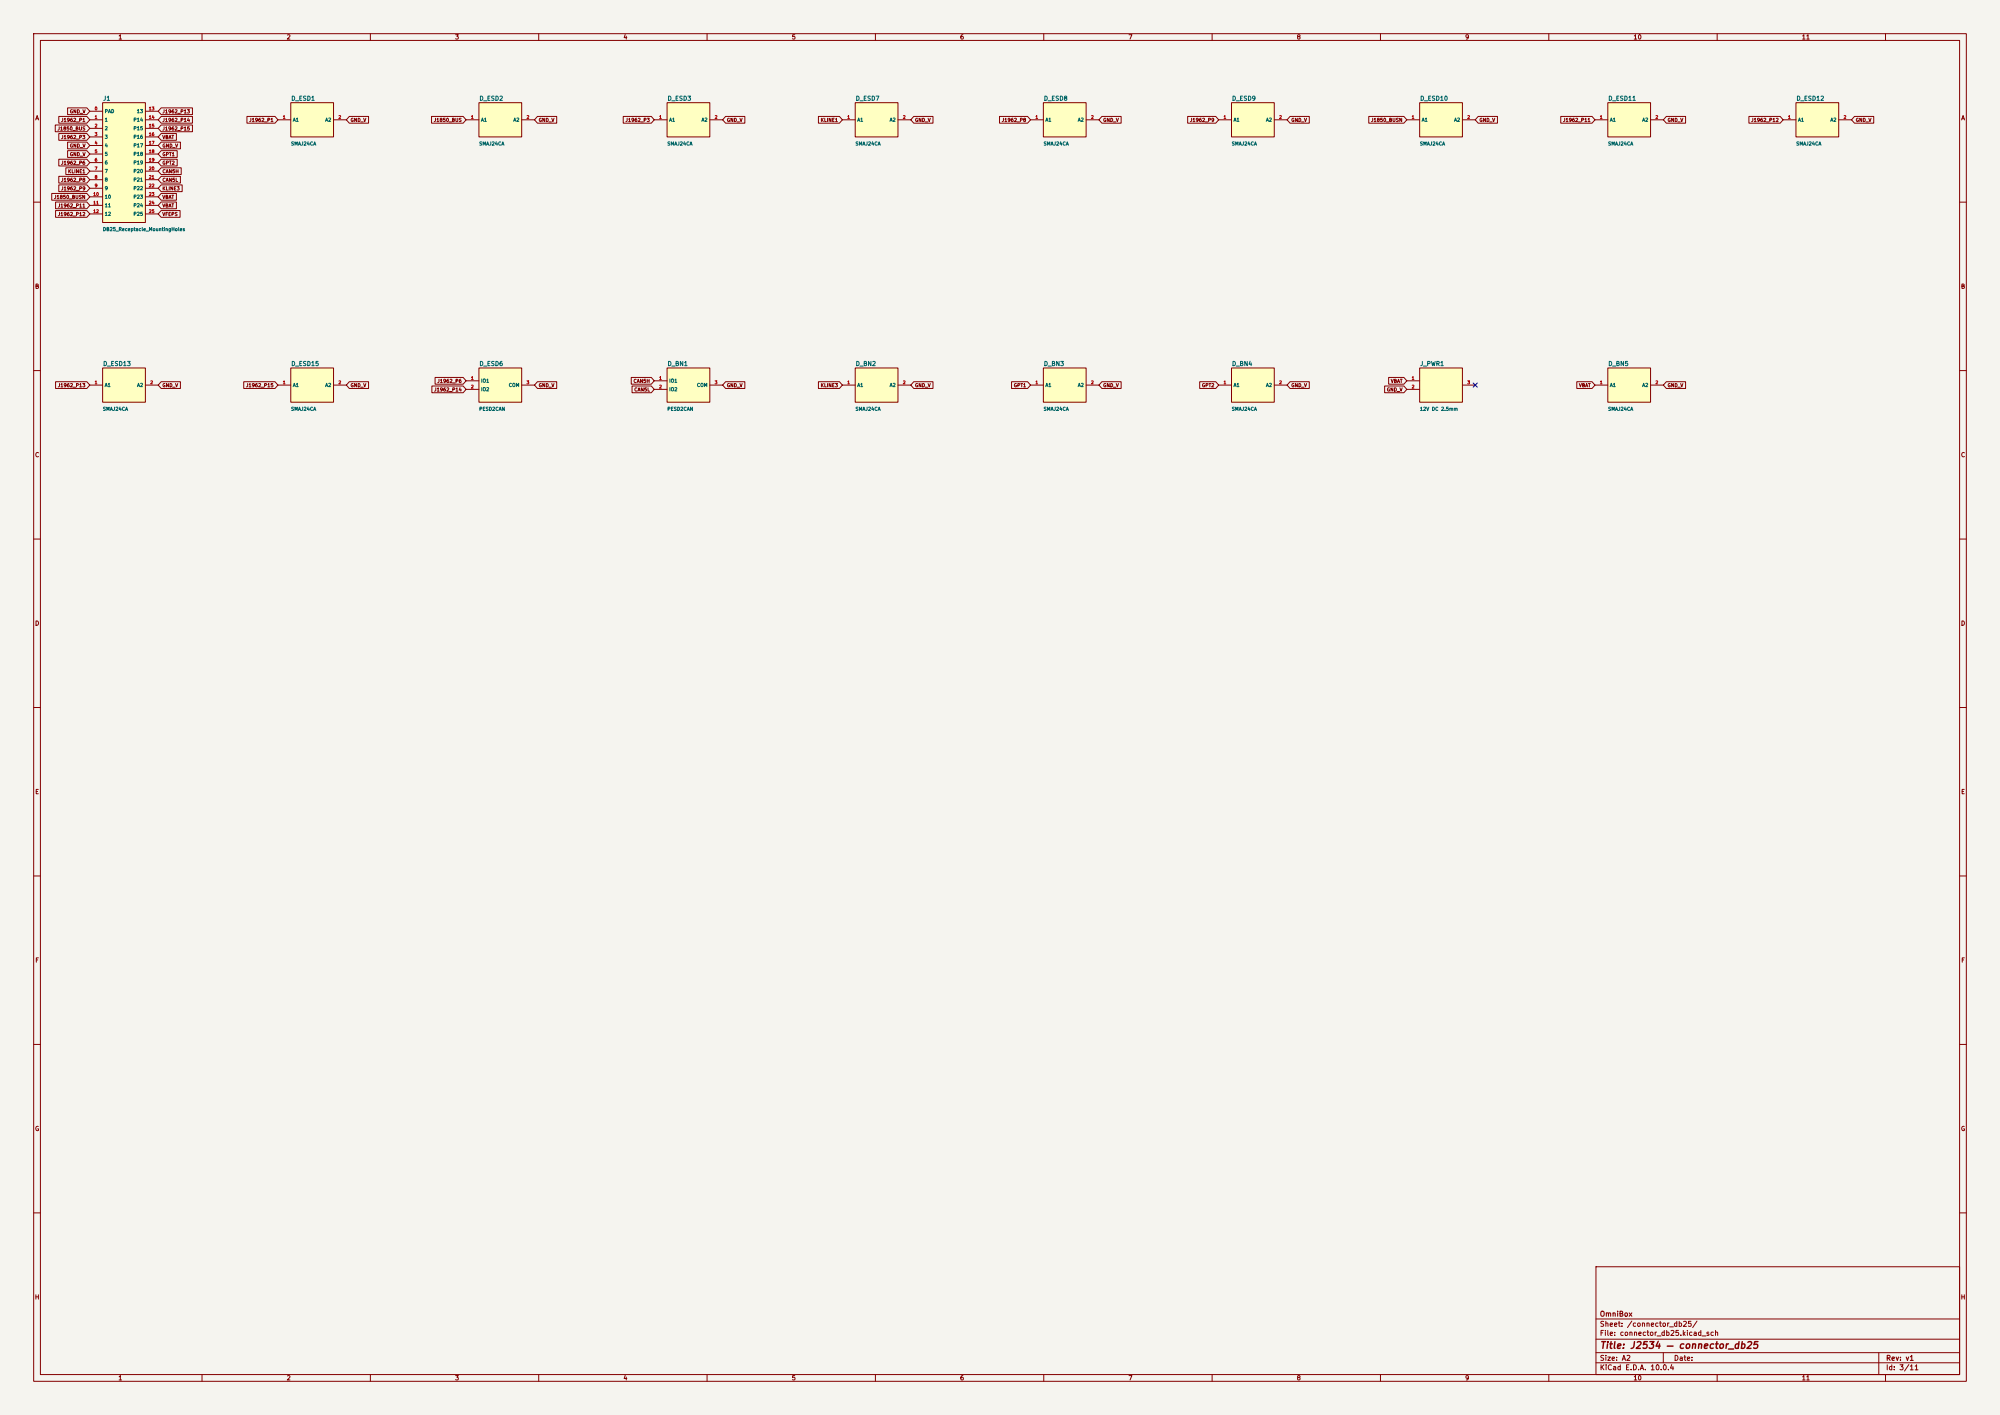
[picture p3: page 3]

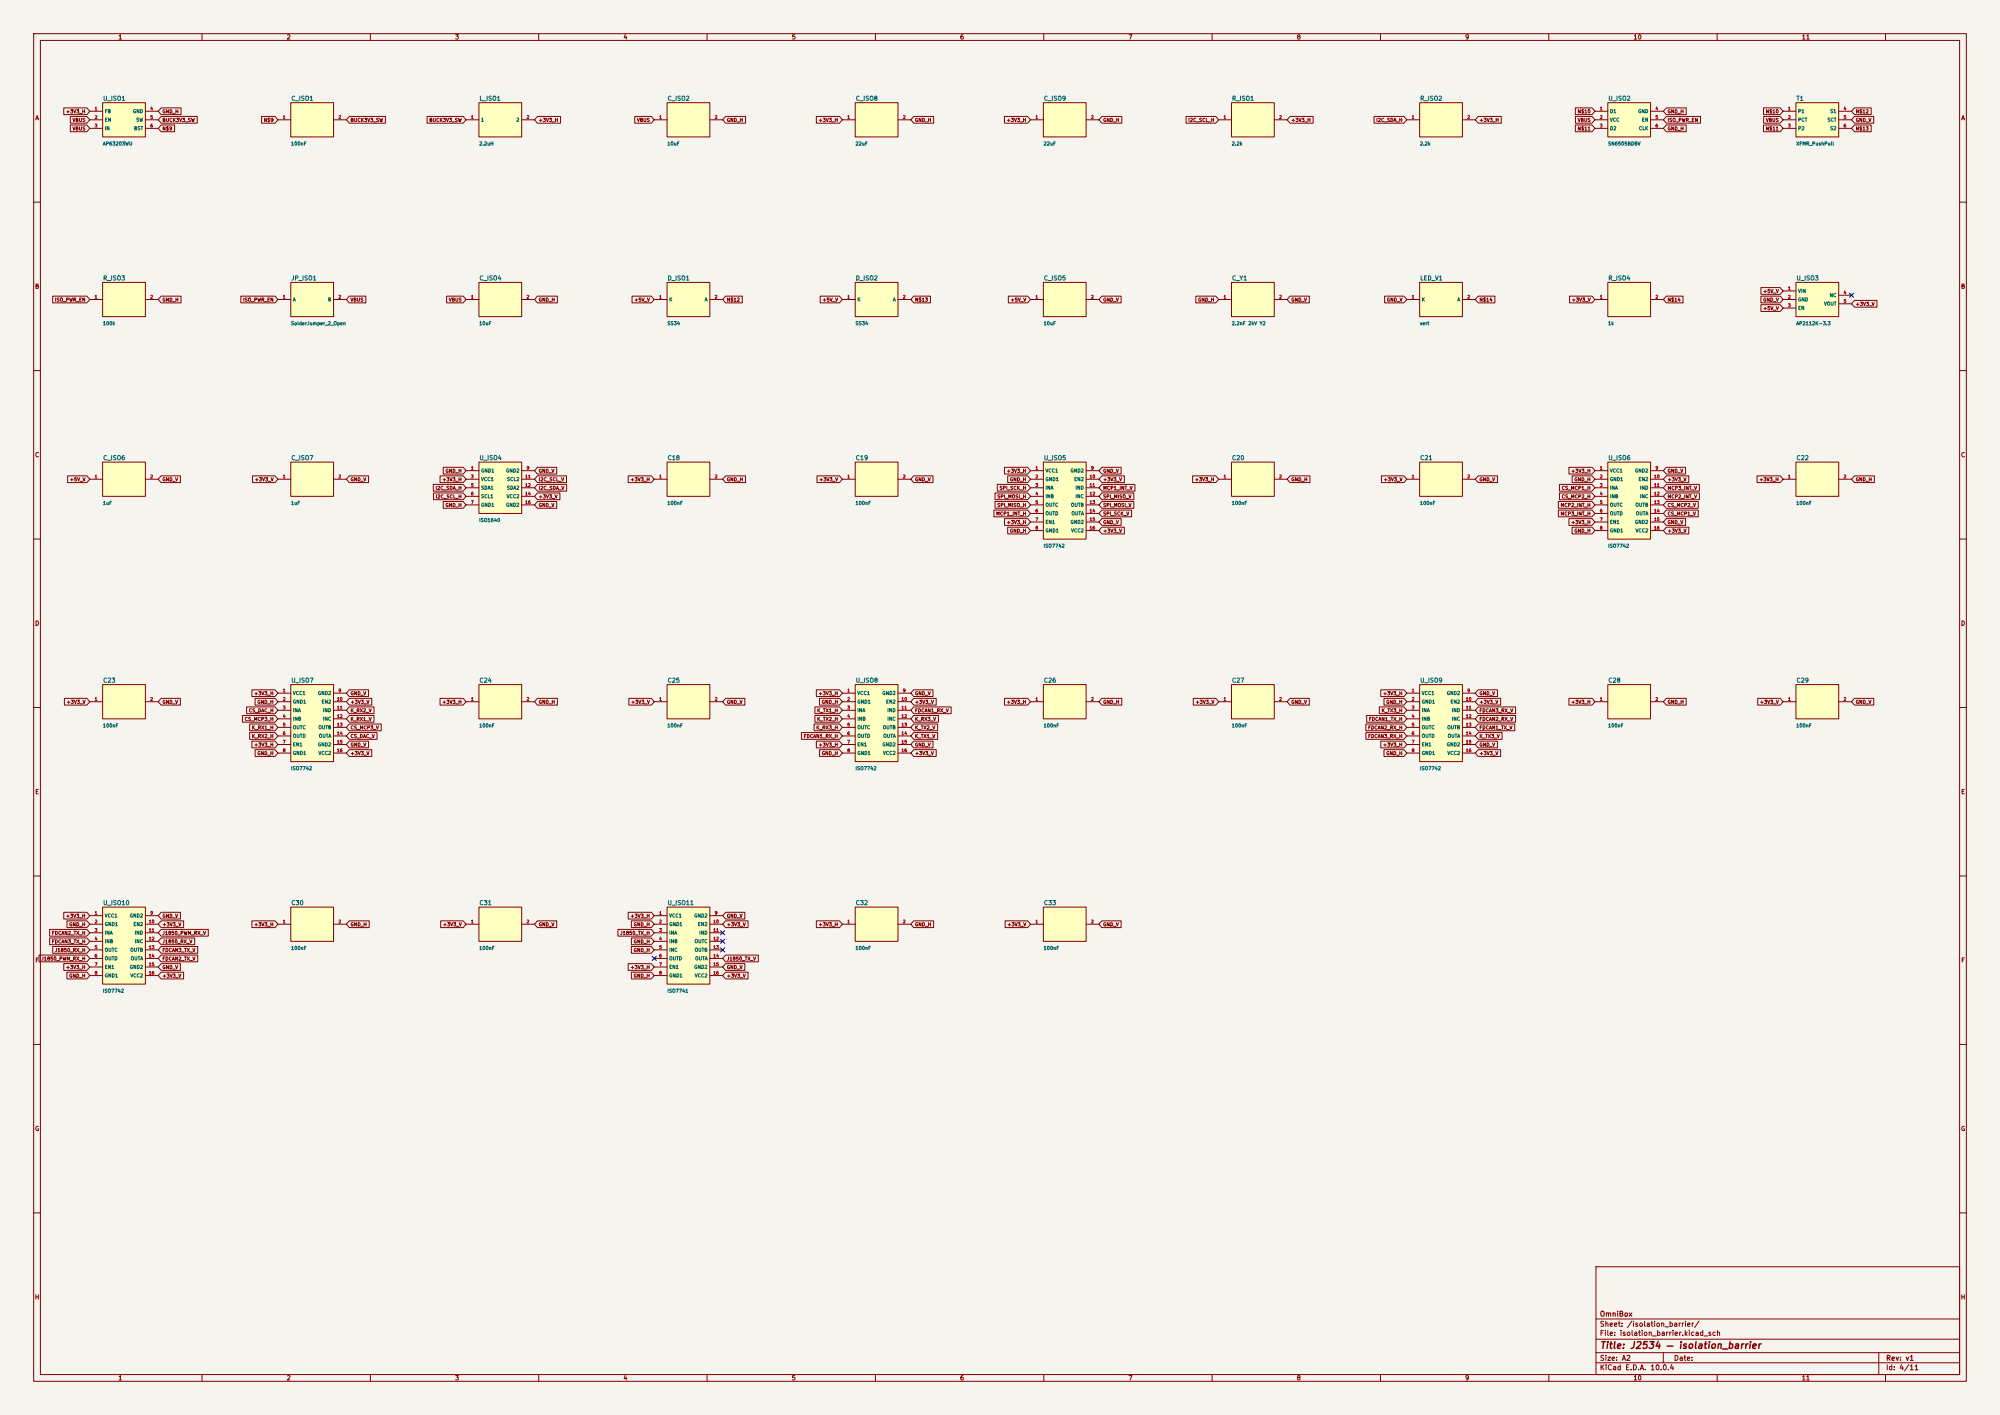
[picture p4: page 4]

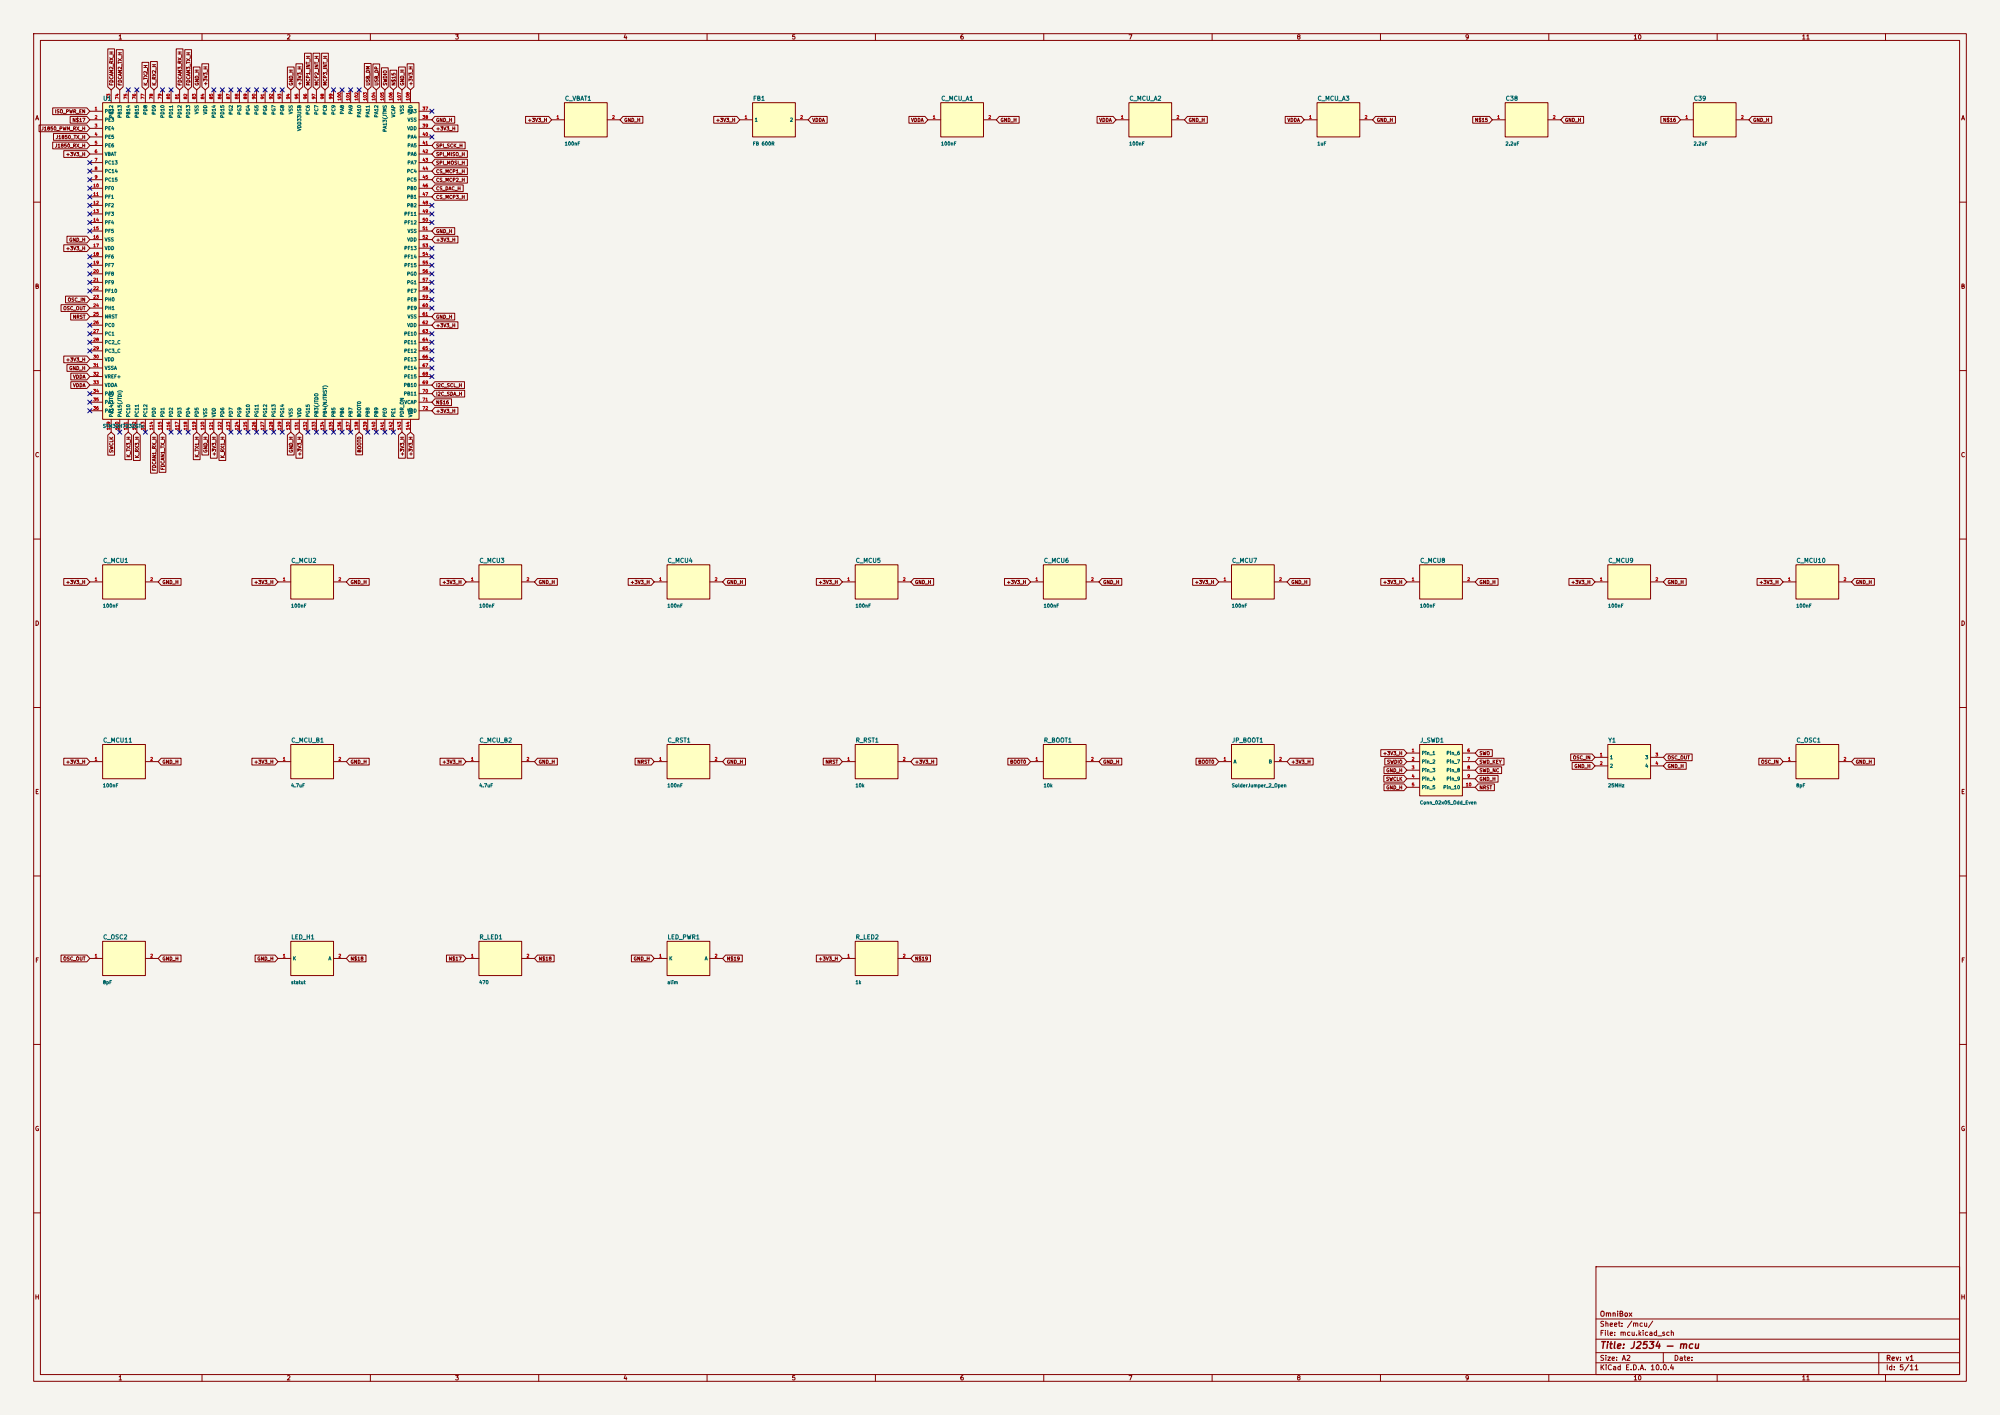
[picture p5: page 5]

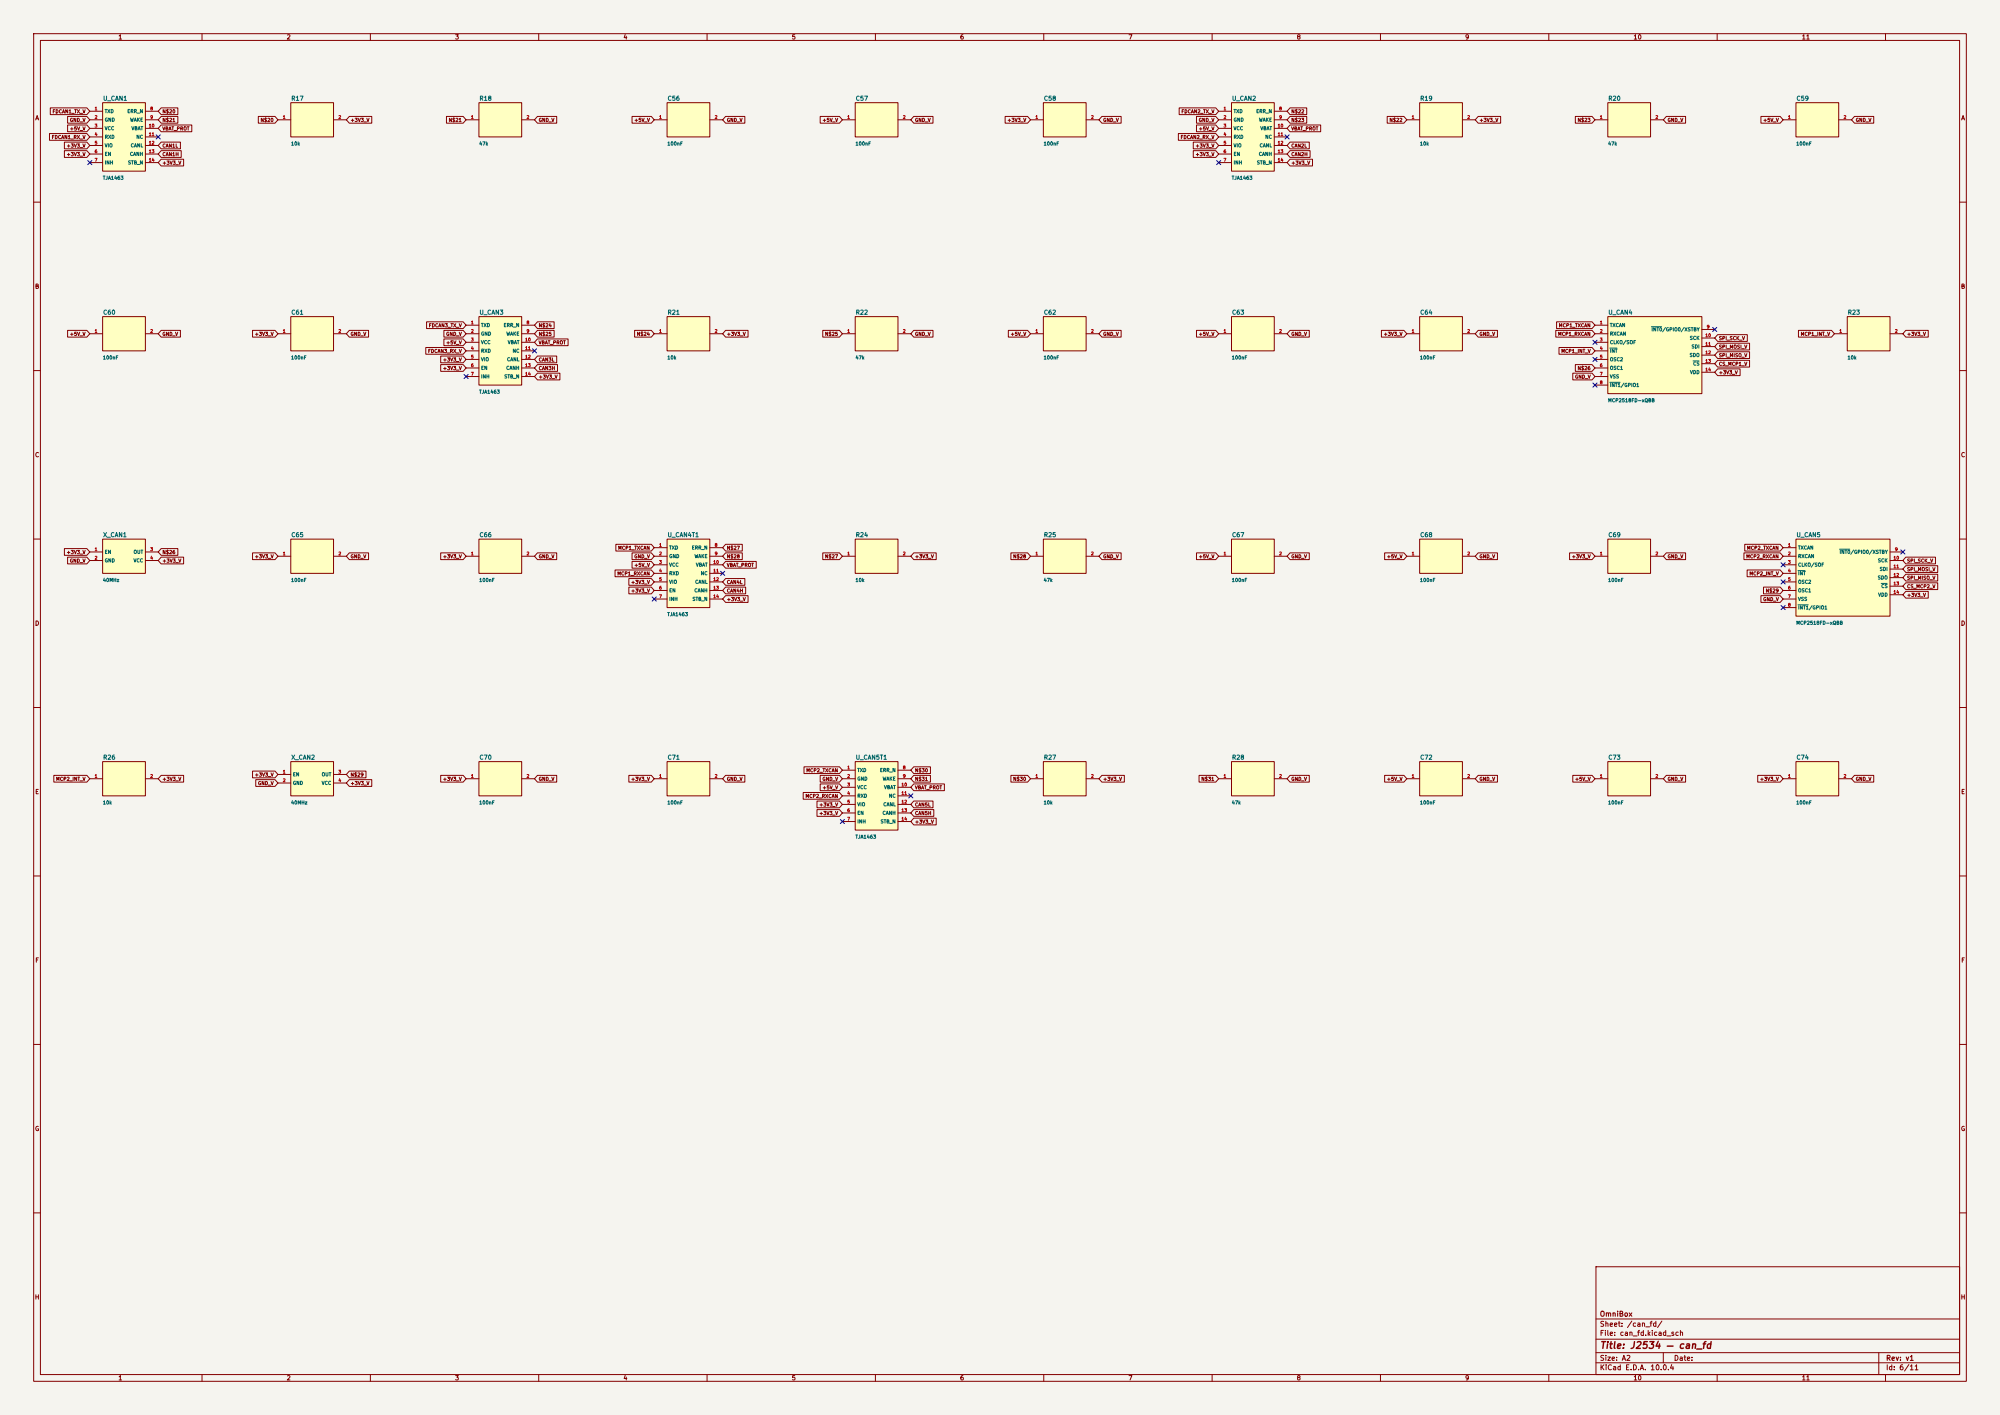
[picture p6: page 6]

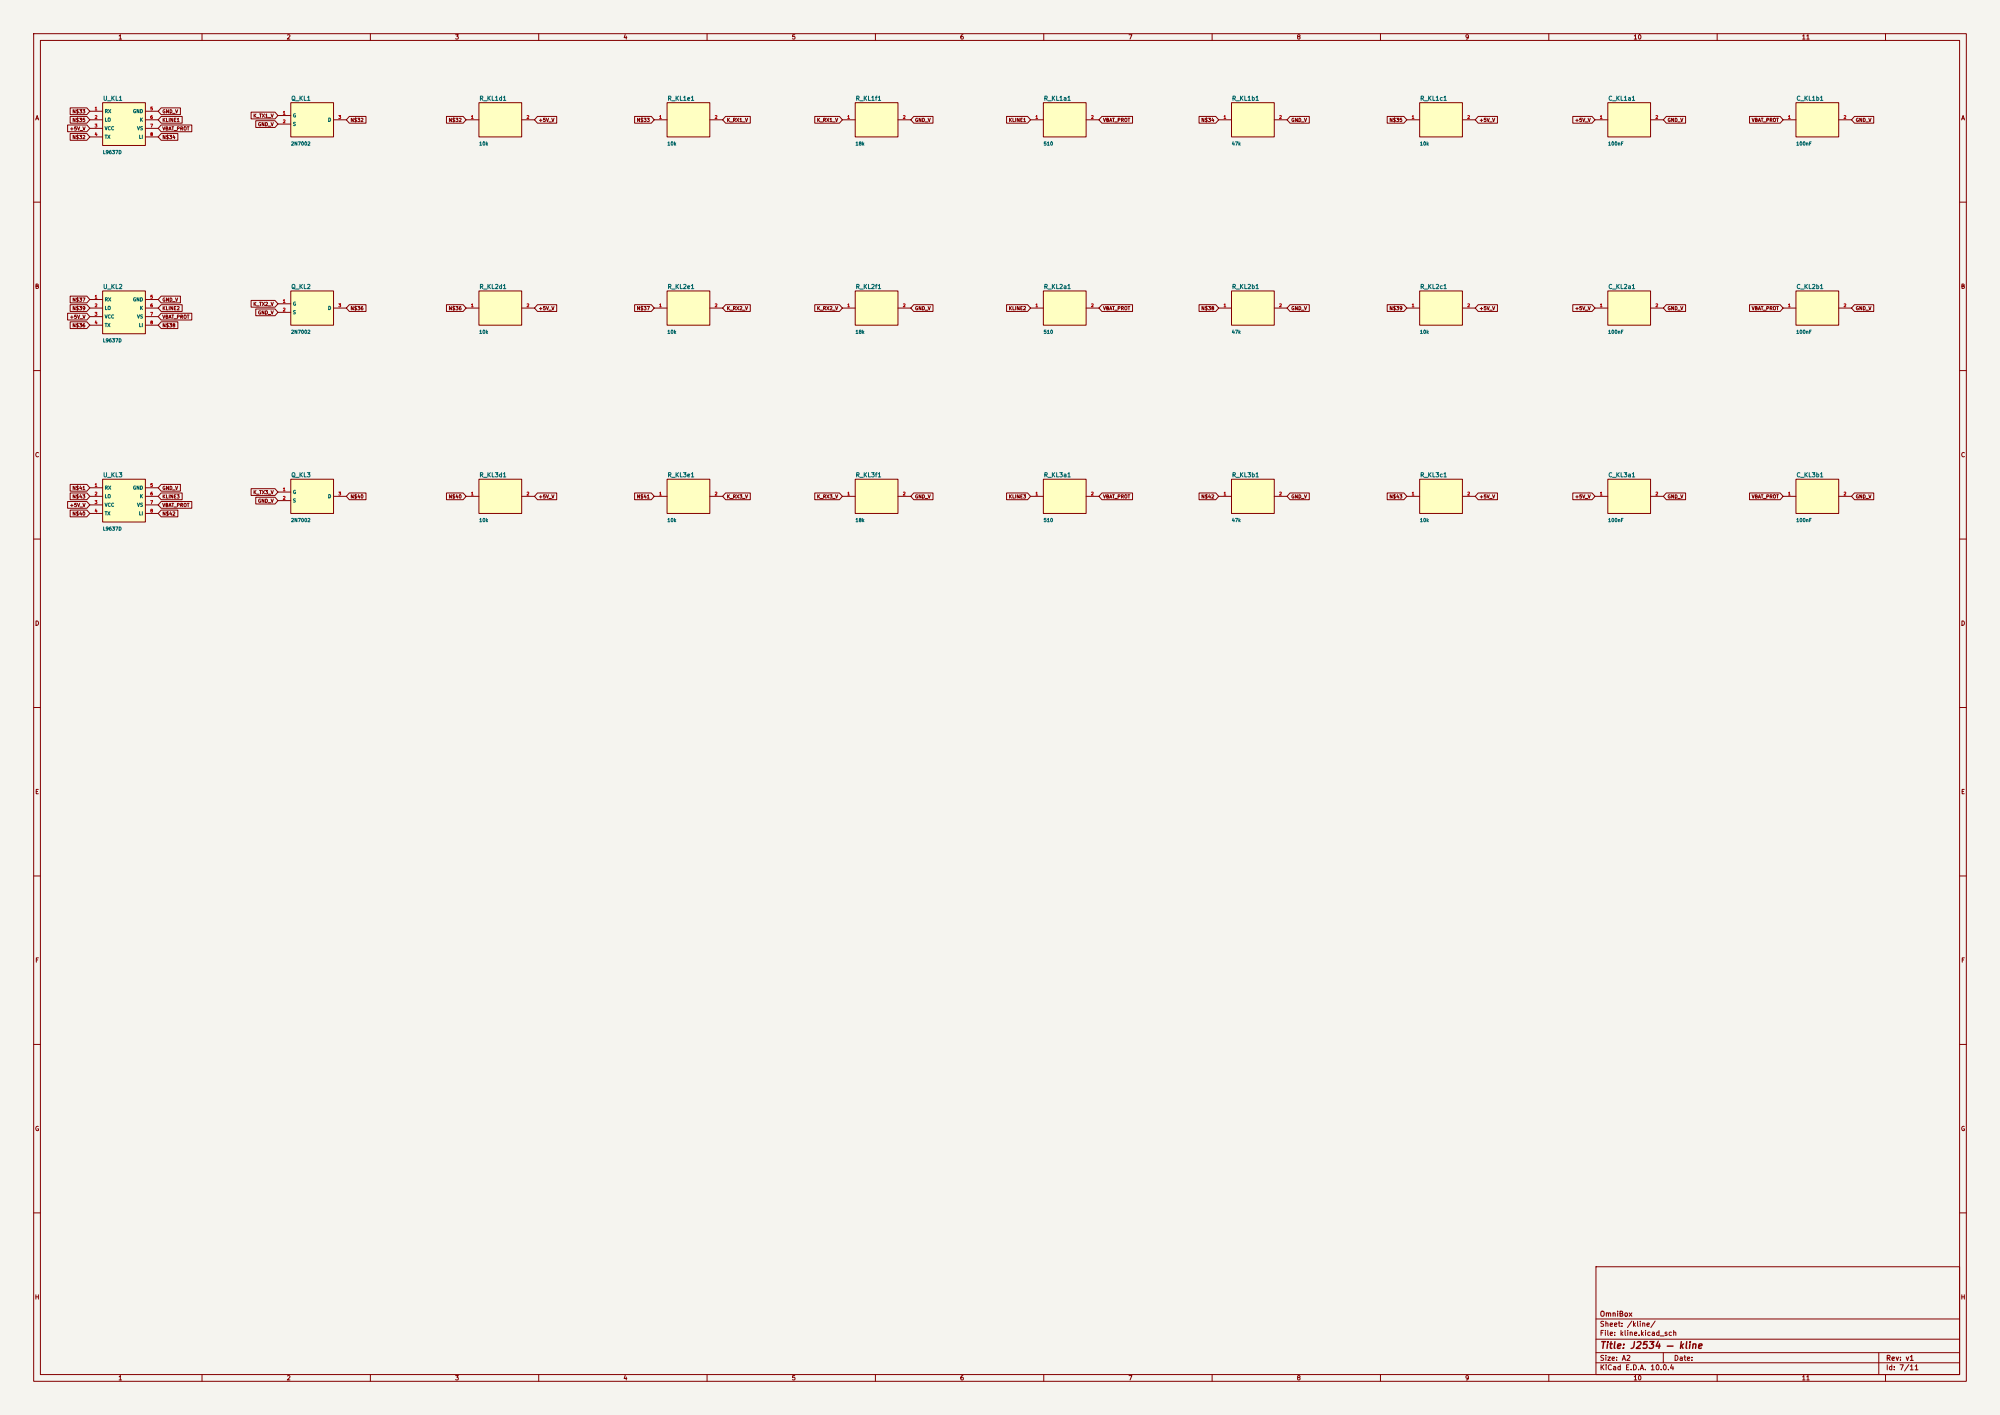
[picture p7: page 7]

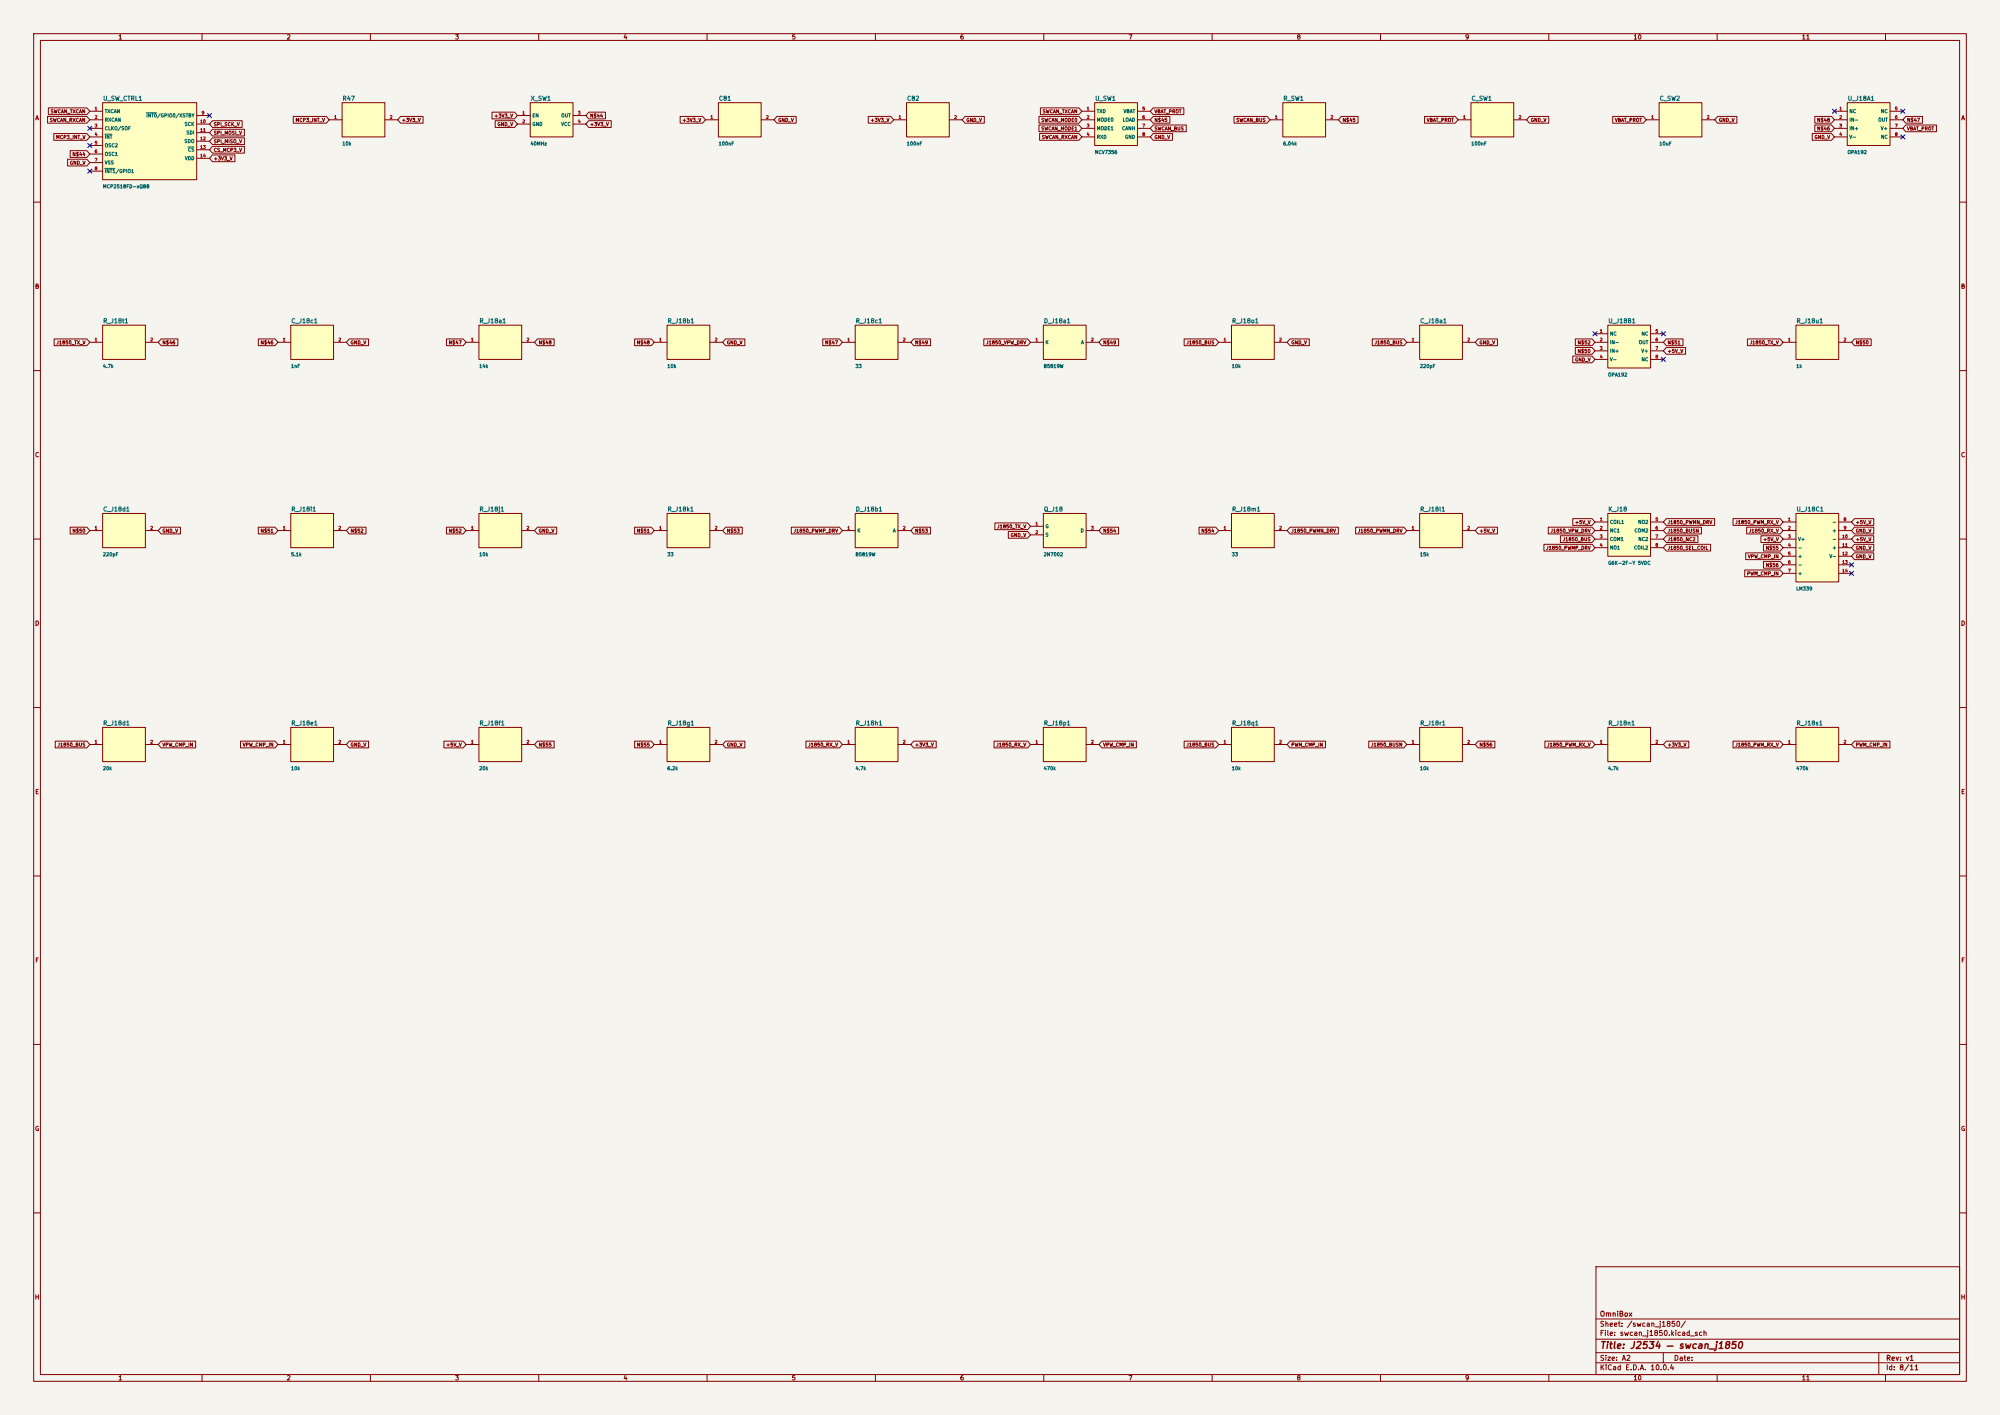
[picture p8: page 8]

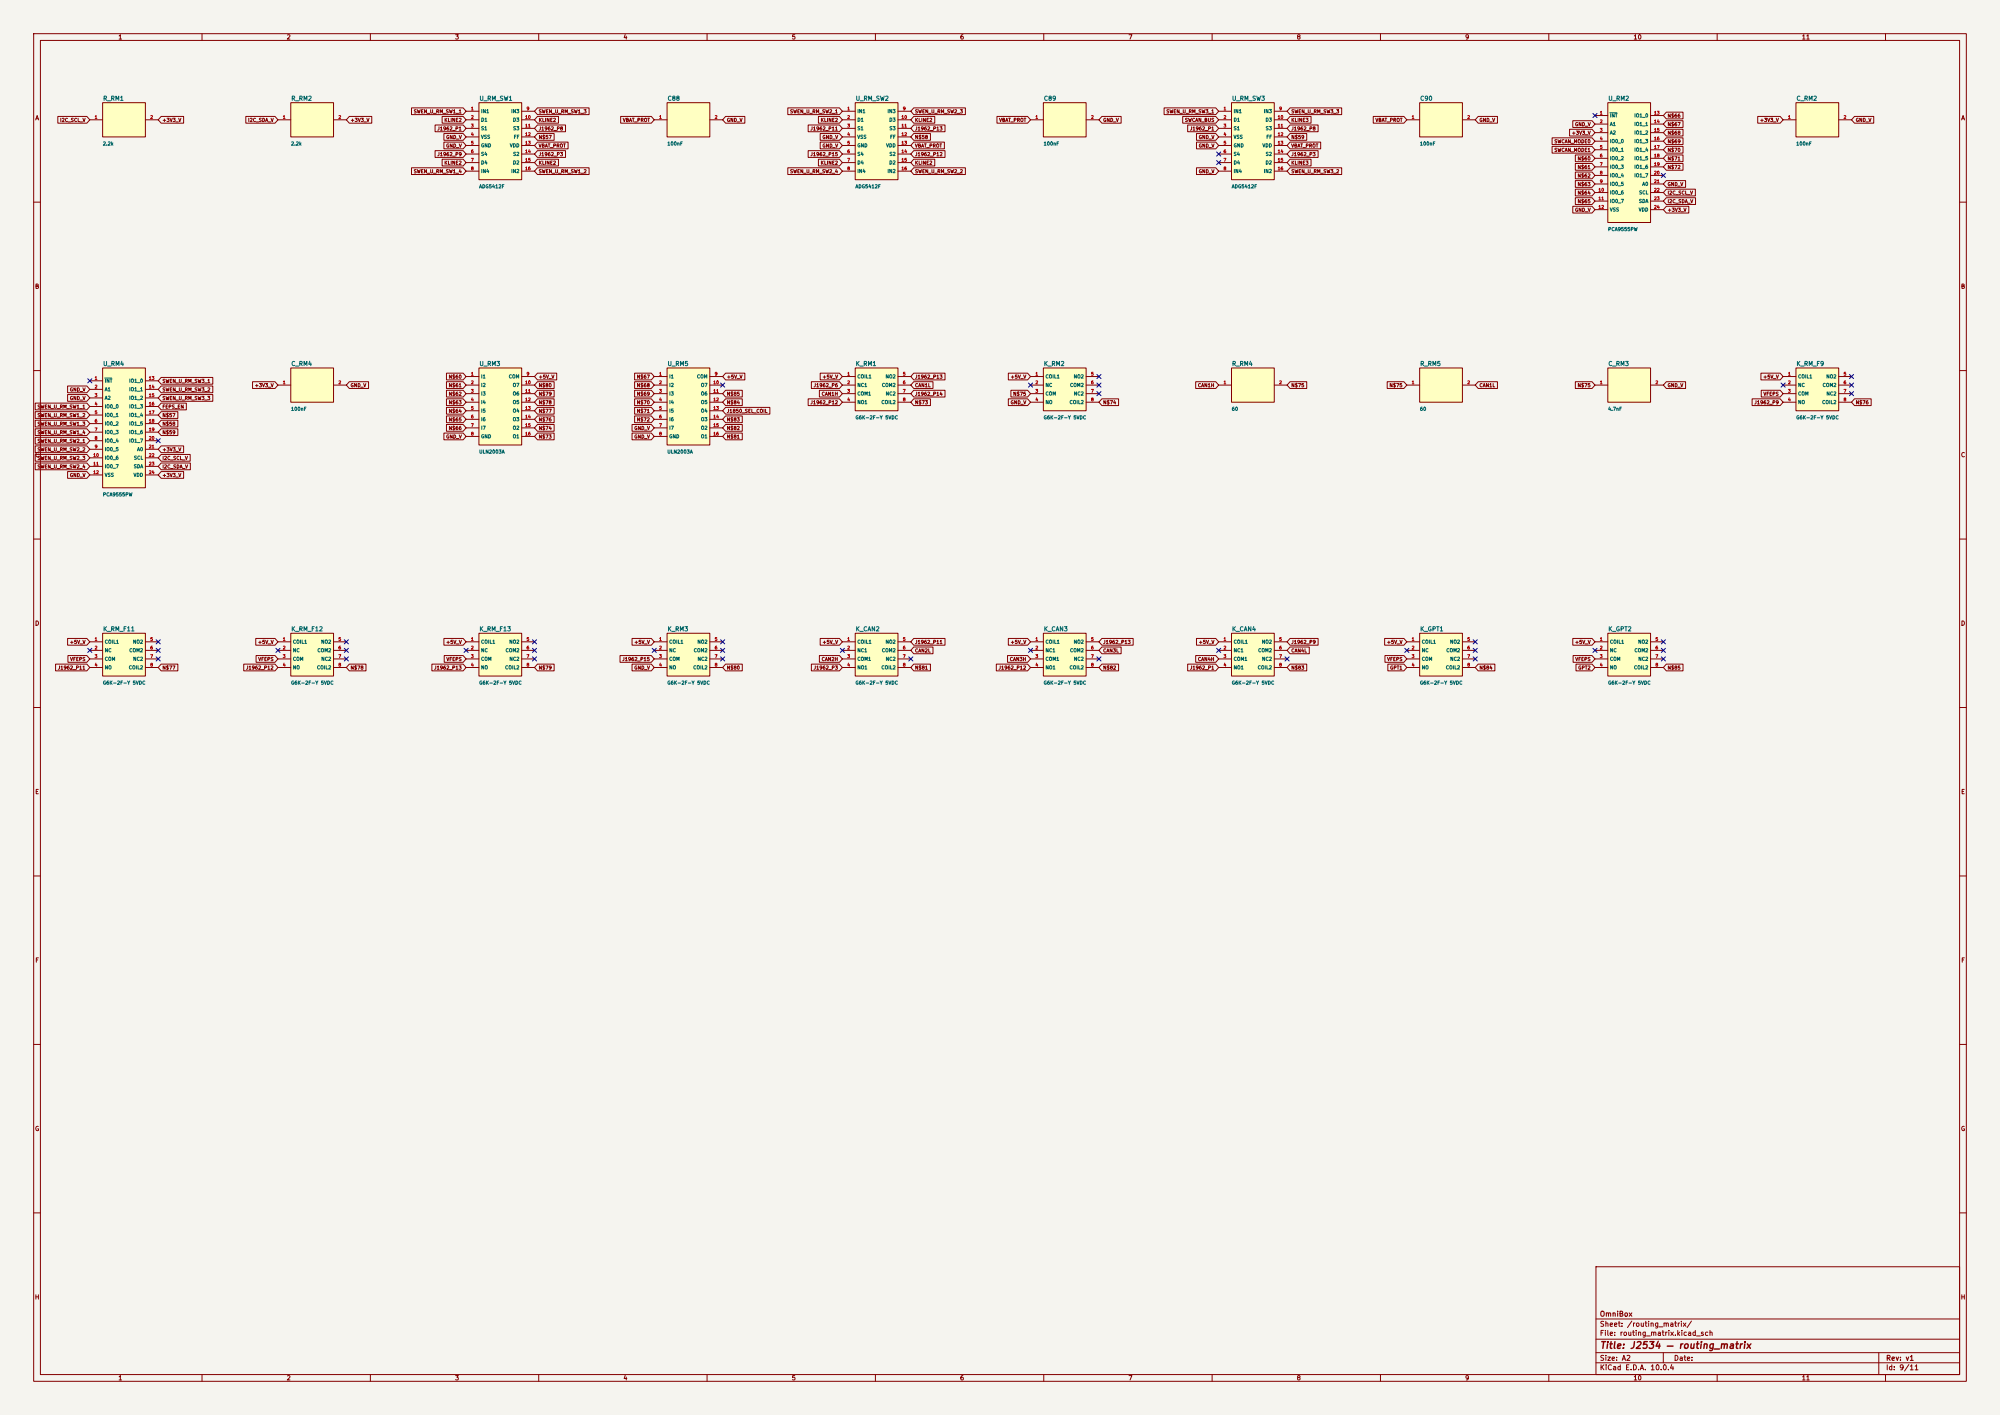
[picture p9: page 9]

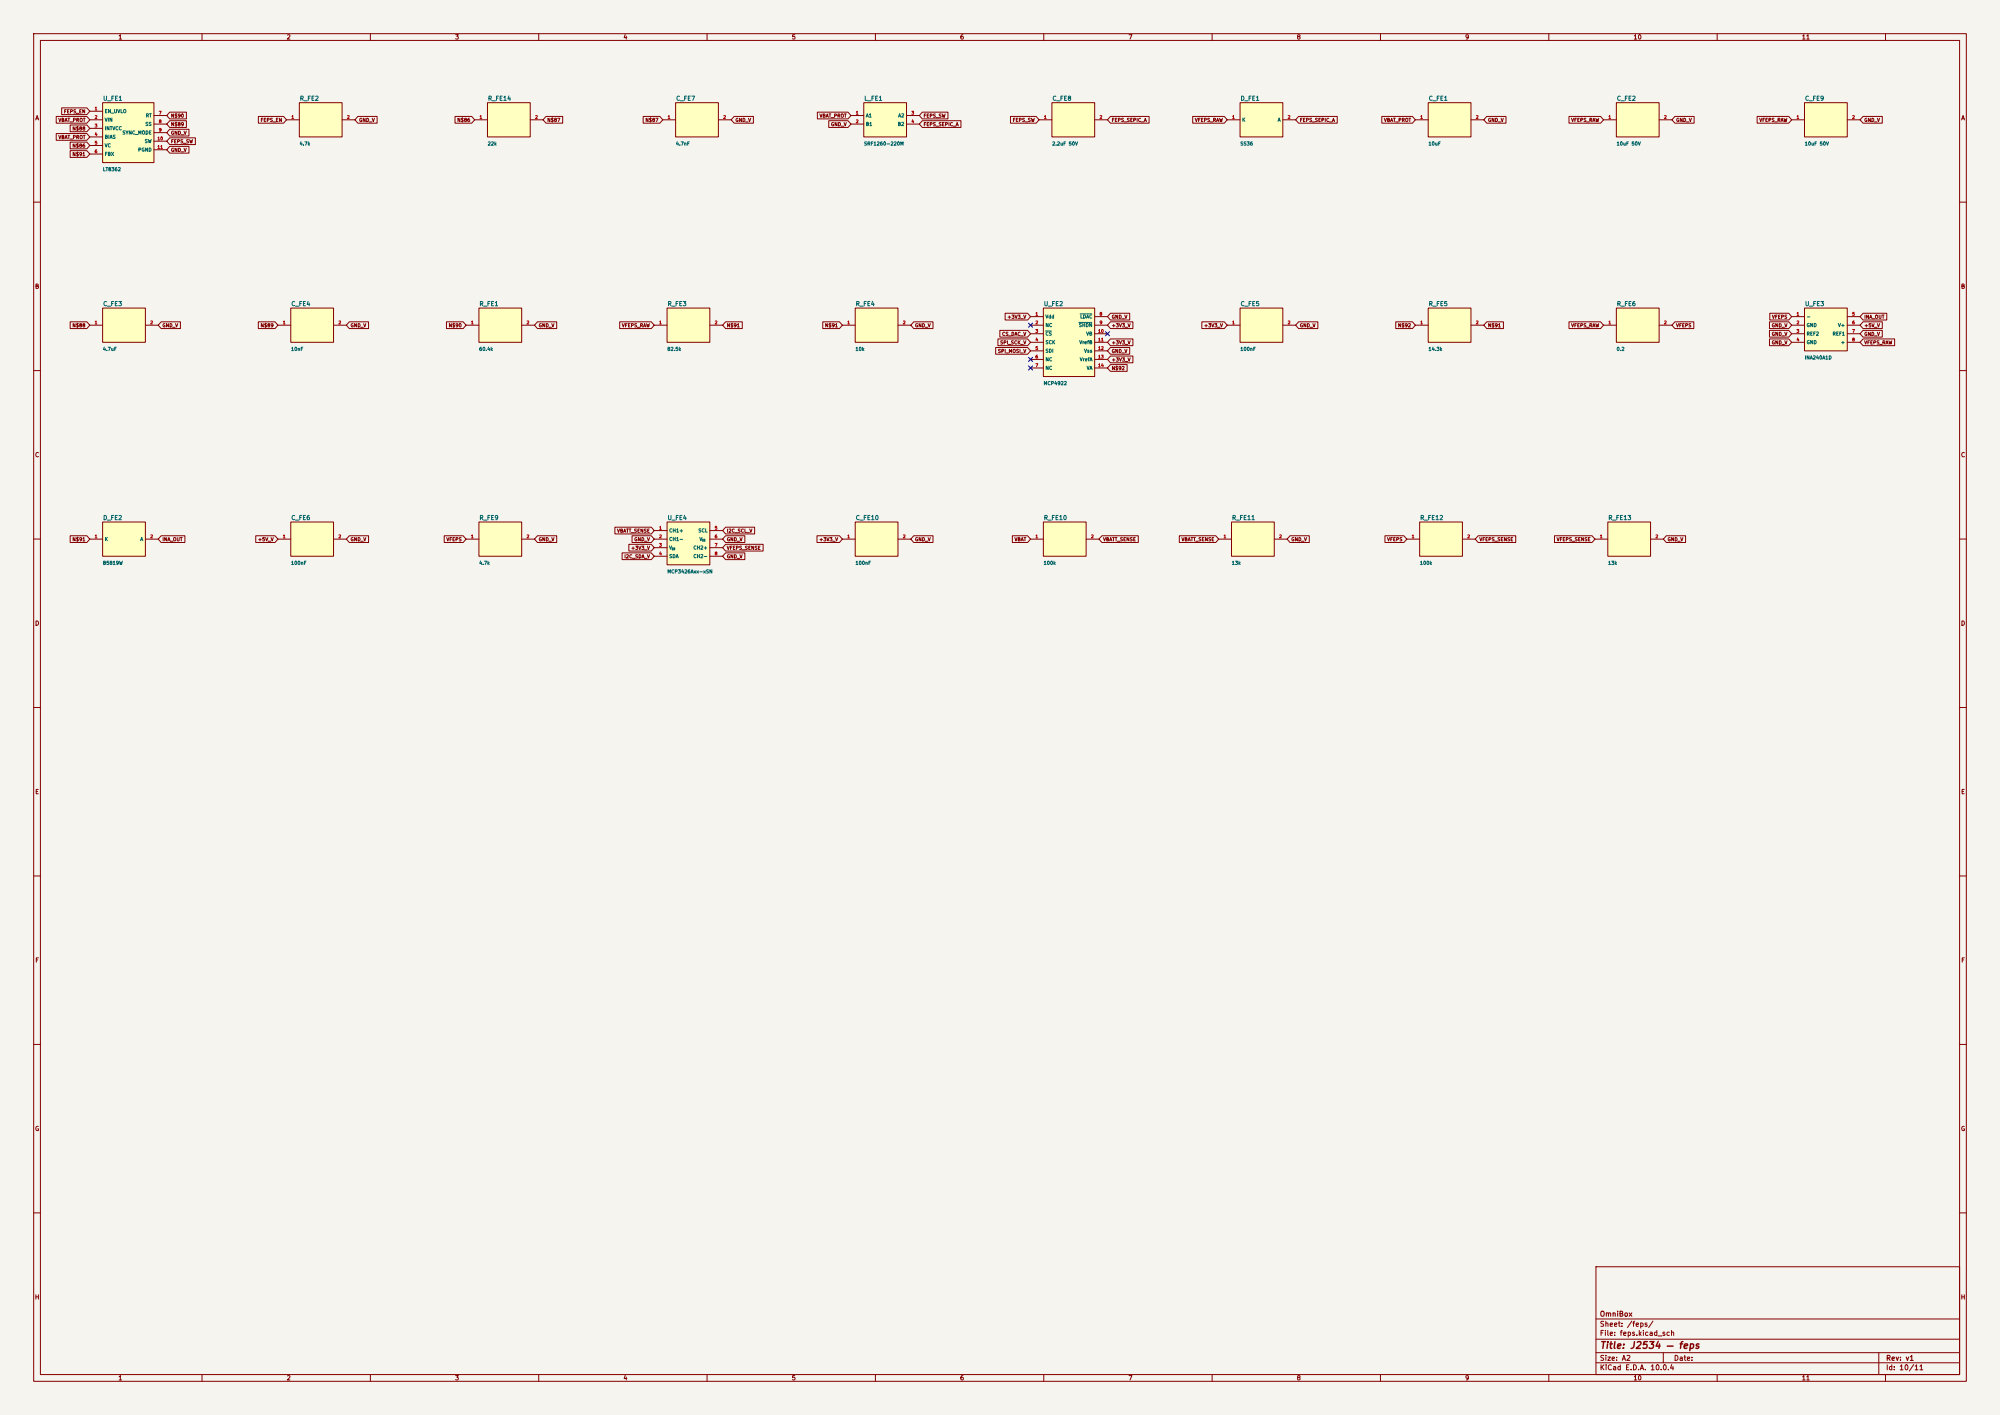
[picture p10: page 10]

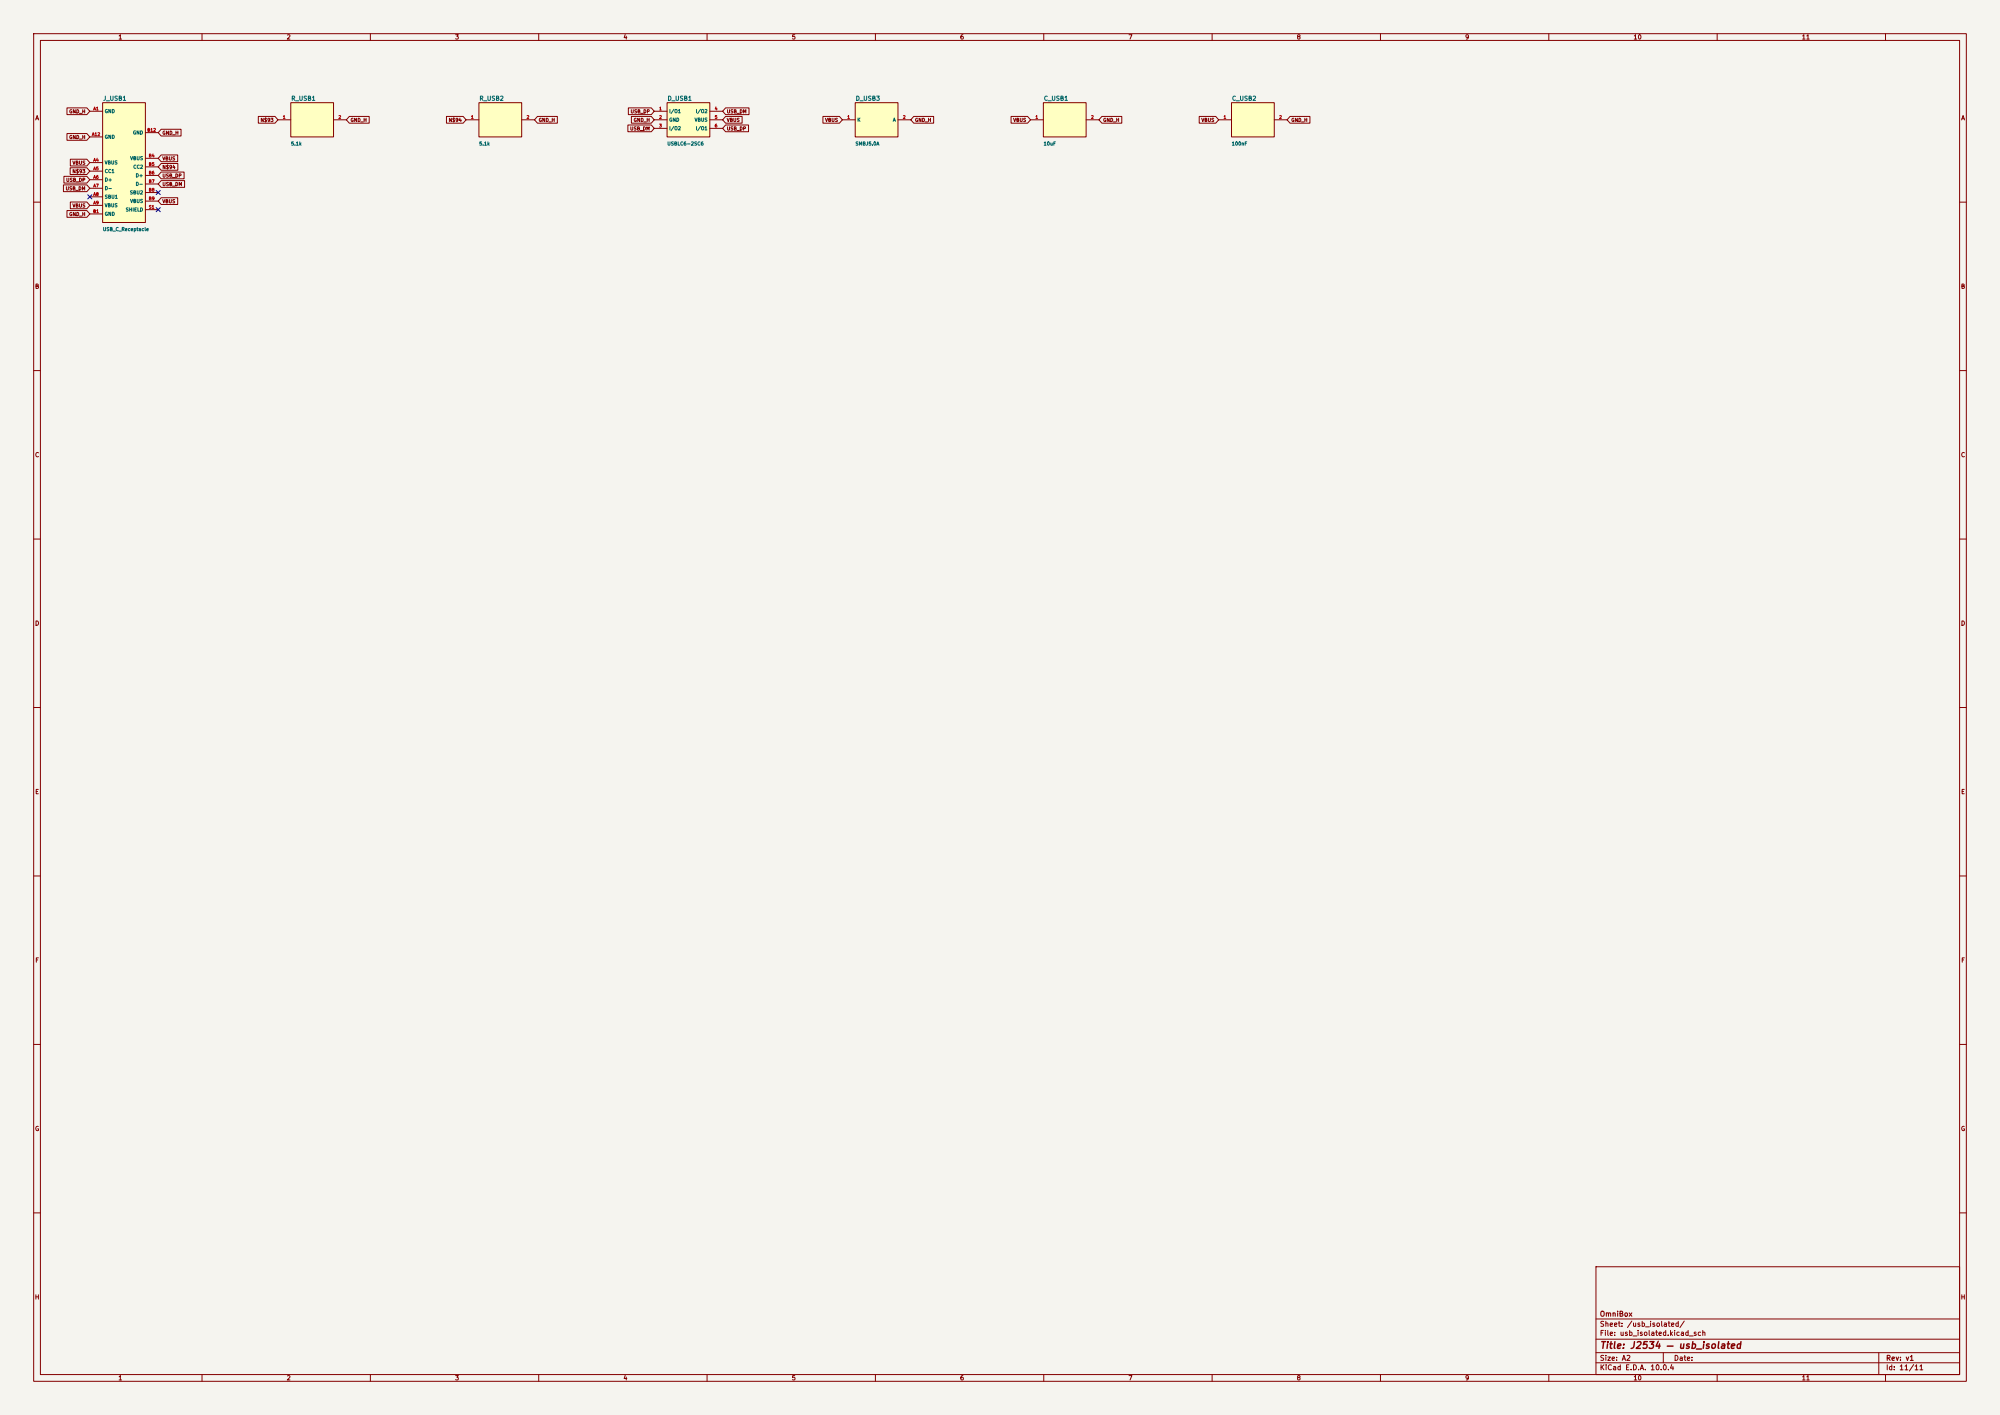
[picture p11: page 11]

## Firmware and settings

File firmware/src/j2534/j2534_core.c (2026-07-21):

#include <string.h>
#include "j2534_core.h"
#include "isotp.h"
#include "kline_asm.h"
#include "trace.h"
#include "../drivers/drivers.h"
#include "../board/board.h"


static void trace_can_frame(uint8_t tag, uint8_t ch, uint32_t id, const uint8_t *d, uint8_t n)
{
  if (!trace_enabled()) return;
  uint8_t b[12];
  b[0] = (uint8_t)(id >> 24); b[1] = (uint8_t)(id >> 16);
  b[2] = (uint8_t)(id >> 8); b[3] = (uint8_t)id;
  uint8_t m = (n > 8u) ? 8u : n;
  for (uint8_t i = 0; i < m; i++) b[4 + i] = d[i];
  trace_record(tag, ch, 0, board_micros(), b, (uint16_t)(4u + m));
}
static void trace_bytes(uint8_t tag, uint8_t ch, const uint8_t *d, uint16_t n)
{
  if (!trace_enabled()) return;
  trace_record(tag, ch, 0, board_micros(), d, n);
}
static void trace_event(uint8_t ch, uint8_t code)
{
  if (!trace_enabled()) return;
  trace_record(TRACE_EVT, ch, code, board_micros(), 0, 0);
}


#define J2534_KLINE_GAP_MS 10u


#define J2534_ISOTP_LINKS 2
#define J2534_ISOTP_BUF  J2534_MSG_DATA_MAX

typedef struct {
  uint8_t in_use;
  uint8_t ch_id;
  uint8_t can_phys;
  uint32_t tx_id;
  uint32_t rx_id;
  uint32_t tx_flags;
  isotp_t tp;
  uint8_t rxbuf[J2534_ISOTP_BUF];
  uint8_t txbuf[J2534_ISOTP_BUF];
  uint32_t next_cf_ms;
  uint32_t n_bs_deadline;
  uint32_t n_cr_deadline;
  uint8_t tx_active;
  uint8_t pad;
} isotp_link_t;

#define J2534_ISO15765_PAD_BYTE 0x00u


#define J2534_N_BS_MS 1000u
#define J2534_N_CR_MS 1000u

static isotp_link_t s_links[J2534_ISOTP_LINKS];
static kline_asm_t s_kasm[KLINE_CH_COUNT];
static j2534_channel_t s_ch[J2534_MAX_CHANNELS];
static int s_open;


static uint8_t s_rx_large[J2534_RX_LARGE_POOL][J2534_MSG_DATA_MAX];
static uint8_t s_rx_large_used[J2534_RX_LARGE_POOL];

static int rx_large_alloc(void)
{
  for (int i = 0; i < J2534_RX_LARGE_POOL; i++)
    if (!s_rx_large_used[i]) { s_rx_large_used[i] = 1; return i; }
  return -1;
}
static void rx_large_free(int idx)
{
  if (idx >= 0 && idx < J2534_RX_LARGE_POOL) s_rx_large_used[idx] = 0;
}

static int is_iso15765(uint16_t proto)
{
  return proto == J2534_ISO15765 || proto == J2534_ISO15765_PS ||
      proto == J2534_SW_ISO15765_PS;
}

static int is_kline(uint16_t proto)
{
  return proto == J2534_ISO9141 || proto == J2534_ISO14230 ||
      proto == J2534_ISO9141_PS || proto == J2534_ISO14230_PS;
}

static int is_j1850(uint16_t proto)
{
  return proto == J2534_J1850VPW || proto == J2534_J1850PWM ||
      proto == J2534_J1850VPW_PS || proto == J2534_J1850PWM_PS;
}


static uint32_t id_be(const uint8_t *d, uint32_t n)
{
  if (n < 4) return 0;
  return ((uint32_t)d[0] << 24) | ((uint32_t)d[1] << 16) |
      ((uint32_t)d[2] << 8) | (uint32_t)d[3];
}

static uint16_t copy_filter_data(uint8_t *dst, const j2534_msg_t *m)
{
  uint32_t n = m ? m->data_size : 0u;
  if (n > J2534_FILTER_DATA_MAX) n = J2534_FILTER_DATA_MAX;
  if (n && m) memcpy(dst, m->data, n);
  return (uint16_t)n;
}

void j2534_init(void)
{
  memset(s_ch, 0, sizeof(s_ch));
  memset(s_links, 0, sizeof(s_links));
  memset(s_rx_large_used, 0, sizeof(s_rx_large_used));
  for (int i = 0; i < KLINE_CH_COUNT; i++) kline_asm_init(&s_kasm[i]);
  trace_init();
  s_open = 0;
  can_init(); kline_init(); j1850_init(); swcan_init(); feps_init(); matrix_init();
}


static void chan_rx_clear(j2534_channel_t *c)
{
  while (c->rx_tail != c->rx_head) {
    rx_large_free(c->rxq[c->rx_tail].large);
    c->rx_tail = (uint16_t)((c->rx_tail + 1) % J2534_RXQ_DEPTH);
  }
  c->rx_head = c->rx_tail = 0;
  c->rx_overflow = 0;
}

static j2534_channel_t *chan(uint32_t id)
{
  if (id >= J2534_MAX_CHANNELS || !s_ch[id].in_use) return 0;
  return &s_ch[id];
}

uint8_t j2534_open(uint32_t *device_id)
{
  if (device_id) *device_id = 1;
  s_open = 1;
  return J2534_STATUS_NOERROR;
}

uint8_t j2534_close(void)
{
  for (uint32_t i = 0; i < J2534_MAX_CHANNELS; i++)
    if (s_ch[i].in_use) j2534_disconnect(i);
  s_open = 0;
  feps_off();
  return J2534_STATUS_NOERROR;
}

uint8_t j2534_connect(uint16_t protocol_id, uint32_t flags, uint32_t baud, uint32_t *channel_id)
{
  if (!s_open) return J2534_ERR_DEVICE_NOT_CONNECTED;
  for (uint32_t i = 0; i < J2534_MAX_CHANNELS; i++) {
    if (s_ch[i].in_use) continue;
    j2534_channel_t *c = &s_ch[i];
    memset(c, 0, sizeof(*c));
    c->in_use = 1; c->protocol_id = protocol_id; c->flags = flags; c->baudrate = baud;
    c->can_phys = 0xFF;
    c->kline_phys = 0xFF;

    switch (protocol_id) {
    case J2534_CAN: case J2534_ISO15765:
    case J2534_CAN_PS: case J2534_ISO15765_PS:
      c->can_phys = CAN_CH1;
      if (can_open(CAN_CH1, baud, baud, flags) != 0) { c->in_use = 0; return J2534_ERR_FAILED; }
      break;
    case J2534_SW_CAN_PS: case J2534_SW_ISO15765_PS:
      c->can_phys = SWCAN_MCP3;
      swcan_set_mode(0);
      if (can_open(SWCAN_MCP3, baud, baud, flags) != 0) { c->in_use = 0; return J2534_ERR_FAILED; }
      break;
    case J2534_ISO9141: case J2534_ISO14230:
    case J2534_ISO9141_PS: case J2534_ISO14230_PS:
      c->kline_phys = KLINE_CH1;
      kline_asm_reset(&s_kasm[KLINE_CH1]);
      kline_asm_set_mode(&s_kasm[KLINE_CH1],
        (protocol_id == J2534_ISO14230 || protocol_id == J2534_ISO14230_PS)
          ? KLINE_MODE_ISO14230 : KLINE_MODE_TIMING);
      kline_open(KLINE_CH1, baud ? baud : 10400); break;
    case J2534_J1850VPW: case J2534_J1850VPW_PS: j1850_set_mode_vpw(1); break;
    case J2534_J1850PWM: case J2534_J1850PWM_PS: j1850_set_mode_vpw(0); break;
    default: c->in_use = 0; return J2534_ERR_INVALID_PROTOCOL_ID;
    }
    if (channel_id) *channel_id = i;
    return J2534_STATUS_NOERROR;
  }
  return J2534_ERR_FAILED;
}


static void free_links_of(uint32_t ch_id)
{
  for (int i = 0; i < J2534_ISOTP_LINKS; i++)
    if (s_links[i].in_use && s_links[i].ch_id == ch_id)
      memset(&s_links[i], 0, sizeof(s_links[i]));
}

uint8_t j2534_disconnect(uint32_t channel_id)
{
  j2534_channel_t *c = chan(channel_id);
  if (!c) return J2534_ERR_INVALID_CHANNEL_ID;
  free_links_of(channel_id);
  chan_rx_clear(c);
  c->in_use = 0;
  return J2534_STATUS_NOERROR;
}



static isotp_link_t *link_alloc(void)
{
  for (int i = 0; i < J2534_ISOTP_LINKS; i++)
    if (!s_links[i].in_use) return &s_links[i];
  return 0;
}
static int link_index(const isotp_link_t *lk) { return (int)(lk - s_links); }
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

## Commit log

2026-07-20 Add 3D board STEP model
2026-07-23 fix(hardware): sync omnibox-v1 with the repaired J2534 V1 KiCad project
    Replace the schematic and board with the corrected, single-source-of-truth
    version from the upstream J2534 V1 project, and consolidate to one project.
    - Schematic + board replaced by the repaired versions (schematic<->PCB relinked
    by symbol UUIDs, 296 (path) links; legal reference designators; library
    prefixes restored on all footprints; USB SuperSpeed pins and MCP2518FD pin 15
    removed to match the fitted footprints; split nets merged: KLINE1/J1962_P7,
    J1850_BUS/J1850_BUSN). Internal project name set to omnibox-v1, company OmniBox.
    - Corrected symbols (sym-lib/j2534gen, j2534_local) and footprint libraries.
    - De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
    [bom-consolide.csv, can_fd.kicad_sch, connector_db25.kicad_sch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]
2026-07-23 docs: add OmniBox V1 hardware test protocol
    494-line bench validation procedure (power, isolation, CAN/K-line/J1850, FEPS); linked from docs/README. Local path genericized.

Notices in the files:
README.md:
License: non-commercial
